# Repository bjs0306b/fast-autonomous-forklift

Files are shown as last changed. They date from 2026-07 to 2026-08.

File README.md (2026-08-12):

# F.A.S.T. — AI 무인 지게차 기반 디지털 트윈 물류 자동화 시스템

카메라와 거리계로 화물을 재고, 그 값으로 적재 위치를 정하고, 무인 지게차가 파렛트에 포크를 꽂아 옮기는 것까지를 한 줄로 이은 시스템이다. 측정·주행·제어·관제·시뮬레이션이 REST와 MQTT 두 가지 방식으로만 대화한다.

SSAFY 15기 공통 프로젝트 (2026-07 ~ 2026-08) · 6인 팀 · 프로젝트 코드 `S15P11A304`

> 실물은 1/10 스케일 미니어처 지게차와 창고다. 화물 측정은 실제 카메라·거리계로 하고, 다중 차량 운영은 Isaac Sim 디지털 트윈으로 시연한다.

---

## 무엇을 만들었나

| 덩어리 | 하는 일 |
|---|---|
| **측정 스테이션** | 지게차에 싣기 전 화물의 치수·전복 위험·편하중을 잰다. 카메라 + 거리계 + 검출 모델 |
| **무인 지게차** | Nav2로 목표까지 자율주행하고, 온보드 비전으로 파렛트 구멍을 찾아 포크를 꽂는다 |
| **클라우드 백엔드** | 작업을 만들고 차량에 배정하며, 측정 결과로 적재 위치를 정한다. 상태를 관제 화면에 중계한다 |
| **디지털 트윈** | 가상 창고에서 다중 지게차를 시뮬레이션하고, 실물 위치를 받아 반영한다 |

**아키텍처 다이어그램 →** [docs/아키텍처-다이어그램.md](docs/아키텍처-다이어그램.md)

---

## 측정한 결과

숫자는 전부 실물에서 잰 값이다. 시뮬레이션이나 공개 데이터셋 성능이 아니다.

| 항목 | 결과 | 목표 |
|---|---|---|
| 화물 치수 오차 | **평균 0.66 mm** / 최대 2.10 mm | ≤ 4 mm |
| 검출 성능 (실물 리그 평가셋) | **mAP@0.5 = 0.9898** (박스 0.9795 / 파렛트 1.0000) | — |
| 온보드 추론 (Jetson Orin Nano) | **GPU 10.18 ms** · 전처리 포함 종단 44.96 ms (22.2 fps) | ≤ 100 ms |
| 파렛트 구멍 검출 재현율 | **99.5 %** (220/221) | — |
| 파렛트 검출 재현율 / 오탐 | **100 %** (105/105) / 네거티브 120장에 **0 건** | — |
| 무인 측정 실물 검증 | 화물 높이 **92.3 mm** vs 실측 91.5 mm (**오차 0.8 mm**) | — |
| 포크 정렬 | **45° 로 돌아간 파렛트에 관통 성공** (재접근 9회, 표본 1회) | — |

---

## 실제로 어떻게 보이나

측정 스테이션이 화물을 보고 판단하는 화면이다. 박스와 파렛트를 각각 잡고, 거리계로 잰 거리로 화면 픽셀을 실치수로 바꾸고, 박스가 파렛트 위 어디에 얹혔는지로 편하중을 판정한다.

| 정상 적재 | 편하중 |
|---|---|
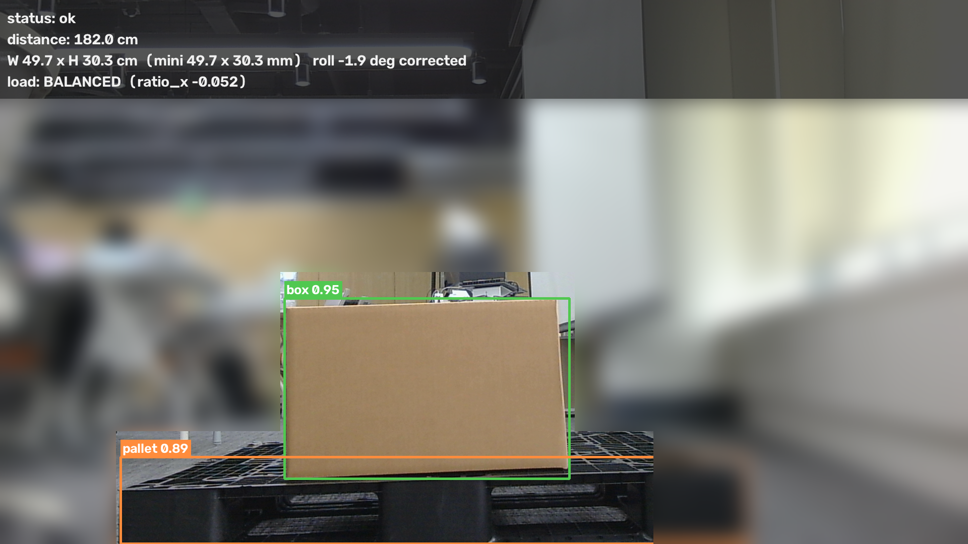
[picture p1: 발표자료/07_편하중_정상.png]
편하중 정상
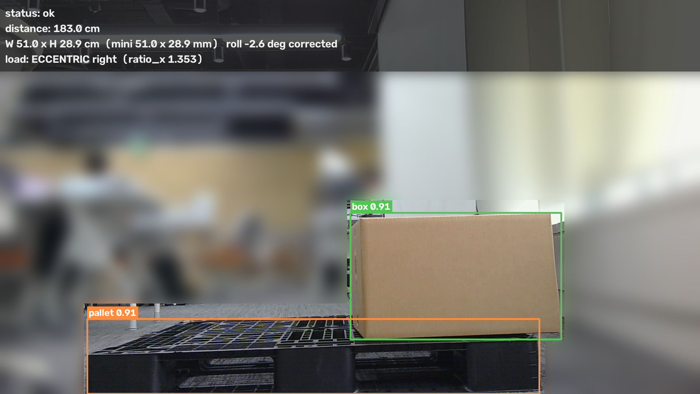
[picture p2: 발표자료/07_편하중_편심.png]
편하중 편심
|  |  |
| `load: BALANCED (ratio_x -0.052)` | `load: ECCENTRIC right (ratio_x 1.353)` |

같은 박스를 파렛트 오른쪽으로 밀어놓은 것만 다르다. 박스 중심과 파렛트 중심의 어긋남을 파렛트 폭으로 나눈 값(`ratio_x`)이 -0.052에서 1.353으로 뛰면서 `ECCENTRIC right`로 넘어간다.

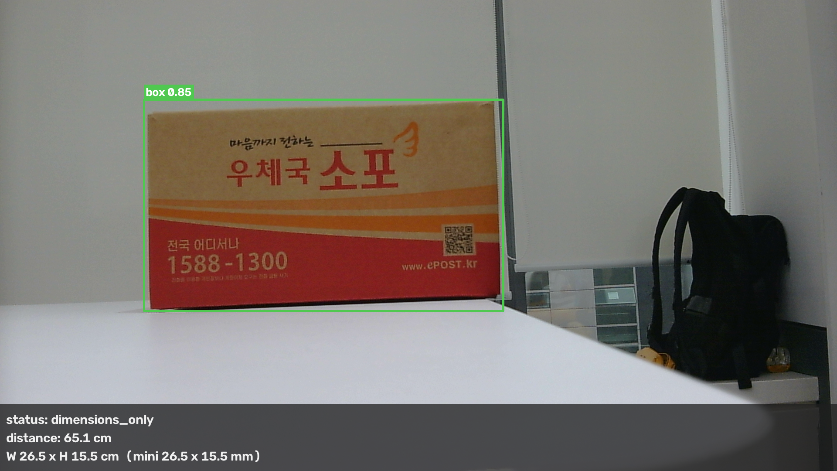
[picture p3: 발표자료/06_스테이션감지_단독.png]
스테이션 검출


파렛트 없이 박스만 있으면 `dimensions_only`로 떨어진다. 치수는 내지만 전복·편하중 판정은 하지 않는다 — 기준이 될 지지면이 없기 때문이다.

---

## 기술 스택

| 영역 | 사용 기술 |
|---|---|
| **AI · 비전** | RTMDet-m / RTMDet-s · MMDetection · MMDeploy · ONNX Runtime · TensorRT FP16 · OpenCV |
| **온보드** | Jetson Orin Nano (JetPack 6 / CUDA 12.6 / TensorRT 10.3) · ROS 2 Humble · Nav2 · AMCL · SLAM |
| **임베디드** | ESP32-S3 · ESP-IDF / FreeRTOS · PCA9685 PWM · MPU6500 IMU · MG996R 서보 |
| **백엔드** | Java 21 · Spring Boot 3.3.4 · MyBatis · MySQL 8 · Spring Integration MQTT (Eclipse Paho) |
| **프론트** | Next.js 16 · React 19 · TypeScript · Tailwind CSS 4 · shadcn/ui · STOMP over SockJS |
| **인프라** | AWS EC2 · Docker Compose · Eclipse Mosquitto 2 (MQTT over TLS) · MediaMTX · GitLab CI/CD · systemd |
| **시뮬레이션** | NVIDIA Isaac Sim 5.1 · Omniverse · USD |

---

## 팀과 기여 범위

6인 팀 프로젝트다. 커밋 이력 기준으로 각자 손댄 영역이 나뉜다.

| 담당 | 이름 | 주 영역 |
|---|---|---|
| **AI · 비전 · 제어** | 방지섭 (본인) | `ai/` · 스테이션 측정 · 온보드 추론 · 포크 정렬 제어 · 조향 펌웨어 |
| 백엔드 · 프론트 | 김재원 | `src/` · `frontend/` |
| 백엔드 · 프론트 | 전지웅 | `src/` · `frontend/` · AI 학습 데이터 수집 |
| ROS 2 · 임베디드 · 하드웨어 | 안제원 | `ros2_ws/` · `firmware/` · `3d_model/` |
| ROS 2 · 임베디드 | 전희창 | `ros2_ws/` · `firmware/` |
| 디지털 트윈 | 이준서 | `isaac_sim/` |

### 본인이 한 것

- **화물 측정 파이프라인** — 카메라·거리계·검출 모델을 묶어 치수·전복 위험·편하중을 내고, 세션을 열어 REST로 백엔드에 올리기까지. 무인 자동 측정(MQTT 트리거 → 정지 대기 → 촬영 → 전송 → 세션 종료)을 실물로 완주시켰다.
- **검출 모델 학습·승격** — 공개 데이터셋에서 시작해 실물 리그·가림 상황까지 도메인을 넓히며 재학습했다. 승격 조건을 착수 전에 못 박고(목표 도메인 지표 / 기존 성능 회귀 없음 / 망각 없음) 셋 다 통과할 때만 교체했다.
- **온보드 추론 이식** — 학습 산출물을 ONNX → TensorRT FP16으로 변환해 Jetson에 올리고, HTTP 추론 서버로 만들어 systemd 자동 기동까지 붙였다.
- **포크 정렬 제어** — 파렛트 구멍 두 개의 화면 좌표에서 좌우 오차와 요각을 기하로 계산해 `/cmd_vel`을 내는 상태기계(SEARCH → APPROACH → ALIGN → VERIFY → INSERT, 실패 시 RETREAT 후 재접근).
- **조향 펌웨어 수정** — 아래 트러블슈팅 참조.

---

## 기술적으로 어려웠던 것

포폴에 남길 값어치가 있는 것은 잘 된 것보다 **틀렸던 것을 어떻게 찾았나**라고 생각해서 세 개만 적는다.

### 1. 제어가 안 먹어서 게인을 이틀 의심했는데, 원인은 서보 펄스 범위였다

포크 정렬이 45° 틀어진 파렛트 앞에서 발산하고, ALIGN 상태에서 요각이 교정되지 않았다. 매끈한 사인파 형태의 진동이라 "폐루프 한계진동"으로 읽고 게인과 감쇠를 계속 만졌다.

실제 원인은 펌웨어의 `SERVO_MIN/MAX_PULSE_US`가 `1000~2000 µs`로 잡혀 있던 것이었다. MG996R은 `500~2500 µs`가 180°라, 코드가 28°라고 믿는 명령이 바퀴에서는 **8°**로만 나왔다 — 명령 대비 실제 회전이 `tan(8°)/tan(28°)` = **21~26 %**. 범위를 고치자 뒷바퀴 실각도가 36°가 되고 45° 파렛트 관통이 됐다.

**얻은 것**: 파라미터를 바꿔도 거동이 안 변하면 제어 루프 **밖**을 본다. 명령 단위와 물리 단위 사이 변환은 한 번은 자로 잰다 — 각도기로 바퀴를 재는 데 5분이면 됐을 일이었다. 이론적으로 옳은 추론(한계진동)이 오히려 조사를 루프 안에 가뒀다.

### 2. 모델이 못 잡는 것은 코드 문제가 아니라 데이터 분포 문제였다 (3회)

같은 종류의 실패를 세 번 겪었다. 책상 클로즈업 박스 미검출, 검은 플라스틱 파렛트가 **임계 0.02에서도 0건**, 화물이 파렛트를 덮으면 score 0.101. 매번 전처리와 임계를 먼저 의심했지만, 셋 다 학습셋에 그 분포가 없어서였다. 마지막 건은 학습셋의 가림률 30% 이상 샘플이 **0장**이었다.

**얻은 것**: 증상을 보면 코드보다 **학습셋 분포를 먼저 세어본다.** 그리고 오탐은 임계 상향이 아니라 기하 조건으로 거른다 — 임계를 0.5에서 0.7로 올리면 재현율이 95.5%에서 91.1%로 같이 깎였다.

### 3. 가장 비싼 버그는 에러를 안 내고 그럴듯한 답을 내는 것이었다

젯슨 추론 서버를 멀티스레드로 띄우자 pycuda의 CUDA 컨텍스트가 생성 스레드에 묶여 매 요청이 실패했는데, **예외가 아니라 검출 0개**로 나가고 서버는 HTTP 200을 응답했다. 클라이언트는 "물체가 없나 보다" 하고 넘어간다. 같은 날 비슷한 것을 다섯 건 더 잡았다 — 경로별 임계 불일치로 `ok`가 조용히 `dimensions_only`가 되고, 정지 판정 임계가 카메라 노이즈 바닥 아래라 "멎었다"가 영원히 성립하지 않고, 녹화 fps에 요청 상한값을 써서 영상이 1.45배 빨리 감겼다.

**얻은 것**: 실패를 성공처럼 보이게 하는 반환값(빈 목록·기본값·상한값)을 그대로 흘리지 않는다. 기동 자가진단을 넣고, 폴백·가정값은 화면과 로그에 항상 표시한다. 임계는 추측하지 말고 노이즈 바닥을 재고 정한다.

---

## 저장소 구조

```
ai/          검출 모델 학습·평가, 측정 스테이션, 온보드 추론, 포크 정렬 제어
src/         Spring Boot 백엔드
frontend/    Next.js 관제 대시보드
ros2_ws/     ROS 2 패키지 (MQTT 브리지, 텔레옵)
firmware/    ESP32-S3 모터 컨트롤러 (ESP-IDF)
isaac_sim/   디지털 트윈 · Nav2 시뮬레이션
infra/       MQTT 브로커 구성
3d_model/    출력용 하드웨어 파츠 (실물 사진 포함)
hardware/    미니어처 박스·파렛트 OpenSCAD 모델
scripts/     배포·점검 스크립트
docs/        설계·검증·운영 문서
발표자료/     발표용 스틸과 원고
```

## 문서

| 내용 | 경로 |
|---|---|
| 아키텍처 다이어그램 | [docs/아키텍처-다이어그램.md](docs/아키텍처-다이어그램.md) |
| 다이어그램 작성 명세 (블록·연결·검증 상태) | [docs/아키텍처-다이어그램-명세.md](docs/아키텍처-다이어그램-명세.md) |
| 요구사항 명세서 | [docs/요구사항명세서.md](docs/요구사항명세서.md) |
| 포크 정렬 설계 근거 | [docs/ai/onboard-fork-align-design.md](docs/ai/onboard-fork-align-design.md) |
| 온보드 TensorRT 절차 | [docs/ai/onboard-tensorrt-runbook.md](docs/ai/onboard-tensorrt-runbook.md) |
| 스테이션 측정 핸드오프 규격 | [docs/ai/station-measurement-handoff.md](docs/ai/station-measurement-handoff.md) |
| 화물 측정 연동 계약 | [docs/backend-message/cargo-measurement-workflow-contract.md](docs/backend-message/cargo-measurement-workflow-contract.md) |
| 관제 화면 와이어프레임 | [docs/와이어프레임-관제화면.md](docs/와이어프레임-관제화면.md) |
| 백엔드 README | [docs/backend-readme.md](docs/backend-readme.md) |
| 스프린트 회고 (KPT) | [docs/KPT/](docs/KPT/) |

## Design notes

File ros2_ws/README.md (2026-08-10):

# FAST ROS2 workspace

현재 패키지는 다음 두 개입니다.

| 패키지 | 역할 |
|---|---|
| `forklift_teleop` | `/cmd_vel`(`geometry_msgs/Twist`)을 ESP32 UART 명령으로 변환하고, ESP32 USB 텔레메트리를 `/imu/data`로 발행 |
| `fast_mqtt_bridge` | ROS2 상태·위치·경로와 백엔드 MQTT 명령/결과 연결 |

빌드:

```bash
cd ros2_ws
rosdep install --from-paths src --ignore-src -r -y
colcon build
source install/setup.bash
```

실행:

```bash
ros2 launch fast_mqtt_bridge mqtt_bridge.launch.py
ros2 launch forklift_teleop teleop_uart.launch.py
ros2 launch forklift_teleop sensor_usb.launch.py
```

`fast_mqtt_bridge`의 상세 설정, MQTT 토픽, 미연결 ROS2 adapter 범위는
[`src/fast_mqtt_bridge/README.md`](src/fast_mqtt_bridge/README.md)를 참고합니다.

LiDAR·좌우 전면 ToF·SLAM·Nav2·장애물 회피·10 Hz Orin 좌표 전송을 한 번에
기동하는 현장 절차는 [`FIELD_SLAM_MQTT.md`](FIELD_SLAM_MQTT.md)를 참고합니다.

## LiDAR AMCL 및 Nav2 통합 현황

2026-07-30 기준 `S15P11A304-98`과 `S15P11A304-99`에서 확인한
실차 위치 추정 및 주행 제어 통합 현황입니다.

### 지도

- 실차 시험 지도 설정: `maps/sim_warehouse_real.yaml`
- 지도 이미지: `maps/sim_warehouse.pgm`
- 해상도: `0.005 m/pixel`
- 지도 원점: `[0.0, 0.0, 0.0]`
- 지도 크기: `400 x 600 pixel` (`2.0 x 3.0 m`)

기존 `my_map.yaml`과 `my_map.pgm`은 이전 AMCL 연동 시험 기록을 위해
유지합니다. 새 실차 시험에서는 `maps/sim_warehouse_real.yaml`을
명시적으로 지정합니다.

지도 원점은 로봇의 출발 위치가 아닙니다. 수신한 지도 픽셀을 분석한 결과
다음 직선 시험 좌표는 장애물로부터 충분히 떨어진 자유 공간입니다.

- 출발 후보: `(x=0.618, y=0.618, yaw=0.0)`
- 가까운 목표 후보: `(x=0.818, y=0.618, yaw=0.0)`
- 이동 거리: `0.20 m`
- 출발점의 장애물 여유 거리: 약 `0.595 m`
- 목표점의 장애물 여유 거리: 약 `0.395 m`

실차 시험에서는 지게차를 지도의 출발 후보에 대응하는 실제 위치와
방향에 놓은 후 `/initialpose`를 발행해야 합니다. 좌표만 입력하고 실차를
다른 장소에 두면 AMCL 위치와 LiDAR 관측이 일치하지 않습니다.

### 확인 완료

- YDLiDAR `/scan` 발행 및 약 11 Hz 수신
- RF2O laser odometry의 `/odom` 발행
- `base_link -> laser_frame`, `odom -> base_link` TF 연결
- map server와 AMCL lifecycle `active`
- `/initialpose` 입력 후 `/amcl_pose` 및 `map -> odom` 생성
- Nav2 controller, planner, BT navigator, velocity smoother lifecycle `active`
- 실측 차체 footprint 적용
- 명시적인 안전 시작점과 목표점을 사용한 `ComputePathToPose` 성공

### 실측 좌표계

`base_link`는 전륜 구동축 중심입니다.

- `base_link`에서 포크 앞쪽 끝: `+0.190 m`
- `base_link`에서 차량 뒤쪽 끝: `-0.245 m`
- 차체 폭: 약 `0.148 m`
- `base_link`에서 LiDAR 중심: `x=-0.025 m`, `y=0.000 m`,
  `z=0.202 m`

차체 footprint:

```text
[[0.190, 0.074], [0.190, -0.074],
 [-0.245, -0.074], [-0.245, 0.074]]
```

### 다음 실차 시험

1. 지게차를 `maps/sim_warehouse_real.yaml`의 출발 후보에 대응하는
   물리적 위치와 방향에 놓습니다.
2. `(0.618, 0.618, 0.0)`을 `/initialpose`로 발행합니다.
3. `/amcl_pose`와 `map -> base_link` TF가 생성되는지 확인합니다.
4. `(0.818, 0.618, 0.0)`을 가까운 시험 목표로 사용합니다.
5. UART 브리지가 실행되지 않았는지 확인한 뒤 `NavigateToPose`를
   실행합니다.
6. 생성된 경로와 `/cmd_vel`만 관찰해 Nav2 비구동 시험을 완료합니다.

UART 비구동 시험 전 확인:

```bash
ros2 node list | grep uart_teleop_bridge
ros2 topic info /cmd_vel -v
```

`/uart_teleop_bridge`가 없어야 하며 `/cmd_vel`에 ESP32 UART 브리지
구독자가 없어야 합니다. 이 상태에서 별도 터미널로 다음 명령을 실행해
Nav2 출력만 확인합니다.

```bash
ros2 topic echo /plan
ros2 topic echo /cmd_vel
```

### 2026-07-30 검증 결과

- `(0.618, 0.618, 0.0)`을 `/initialpose`로 입력해 AMCL pose와
  `map -> odom -> base_link` TF 생성을 확인했습니다.
- 안전한 시작점과 목표점을 지정한 `ComputePathToPose`가 성공했습니다.
- Nav2 controller, planner, BT navigator, velocity smoother가 모두
  `active` 상태로 전환되는 것을 확인했습니다.
- 축거 `0.144 m`를 사용하는 후륜 조향 Ackermann 곡률 변환을 적용하고
  Python 단위 테스트 29개가 통과했습니다.
- 바퀴를 띄운 상태에서 수동 `/cmd_vel`을 UART 브리지로 전달해 전진,
  좌·우 조향, 정지 및 서보 중앙 복귀를 확인했습니다.
- DC 모터와 서보를 동시에 구동했으며 UART CRC/ACK 왕복 통신이
  정상적으로 유지됐습니다.
- `/cmd_vel` 발행 중단 후 500 ms watchdog에 의해 DC 모터가 자동으로
  정지하고 서보가 중앙으로 복귀하는 것을 확인했습니다.

### 2026-08-05 갱신 — 조향 실각도가 명령의 1/4이었다

`ros2_ws` 밖(펌웨어)의 문제였지만 **여기의 곡률 변환 전제가 깨져 있었다**.
`servo.c`가 각도를 180으로 정규화해 `SERVO_MIN/MAX_PULSE_US` 사이에 매핑하는데
그 범위가 `1000~2000 µs`였다. MG996R은 **500~2500 µs가 180°**다.

- 최대 조향을 명령했을 때 뒷바퀴 실측 **8°** (코드가 믿던 값 28°)
- 실효 회전반경 **1200~1450 mm** (설계값 537 mm의 2~3배)
- 명령 대비 실제 회전 **21~26%** = `tan(8°)/tan(28°)`

수정 후 값(`config/teleop.yaml`이 단일 출처):

| 항목 | 값 |
|---|---|
| 서보 펄스 범위 | `500~2500 µs` |
| `rear_steering_limit_deg` | `36.0` |
| `steering_center_cdeg` | `9000` (직진 편차 0.33°) |
| `steering_min/max_cdeg` | `5400 / 12600` (±36° 대칭) |
| `max_angular_rps` | `0.75` |
| `max_drive_percent` / `_reverse` | `60` / `100` |

⚠️ **조향 한계가 네 곳에 서로 다른 값으로 박혀 있었다.** `protocol.py`의 하드코딩이
범위 밖 명령에 `ValueError`를 던져 **브리지 프로세스를 죽이고 있었다**(증상은
"조향이 아예 안 움직임" — `/cmd_vel` 구독자가 사라진다). 지금은 **봉투**(`protocol.py`
·펌웨어)와 **운전값**(`teleop.yaml`)이 분리돼 있어 범위를 바꿔도 재플래시가 필요 없다.

⚠️ **경로 추종 게인을 이 이전에 잡았다면 다시 봐야 한다.** 같은 `angular_z`가 이제
4.5배로 돈다.

### 남은 실차 검증

- `NavigateToPose -> /cmd_vel -> UART bridge -> ESP32`를 동시에 연결한
  저속 자동 주행
- 🔴 **`/cmd_vel` 인계 규칙**(S15P11A304-**199**) — **셋이 얽혀 있다**(2026-08-06 갱신):

  | 주체 | 하는 일 |
  |---|---|
  | Nav2 | `/cmd_vel` 에 주행 명령 발행 |
  | `obstacle_avoidance`(109) | `/cmd_vel` 을 받아 감속·정지시켜 **`/cmd_vel_safe`** 로 중계 |
  | 포크 정렬(`onboard_fork_align_node.py`) | `/cmd_vel` 에 직접 발행 |

  ⚠️ **guard 를 띄우면 브리지가 `/cmd_vel_safe` 만 듣는다**(`obstacle_avoidance.launch.py`가
  `cmd_vel_topic` 을 덮어쓴다). 그 상태에서 포크 정렬은 guard 를 통과하게 되는데,
  guard 는 **0.45m 에서 정지 · 1.00m 부터 감속**한다. 정렬은 0.70m 에서 시작해 **0.21m 까지**
  들어가야 하므로 **파렛트를 장애물로 보고 막는다.** guard 가 틀린 게 아니라 역할이 겹친 것이다.

  지금 운용: 정렬 시간에는 Nav2 와 guard 를 내리고 `teleop_uart.launch.py` 로 브리지만 띄운다
  (`docs/ai/onboard-fork-align-runbook.md` §1·§1-2). 정렬 노드를 guard 뒤에 붙이려면
  `--cmd-topic /cmd_vel_safe`.
- ~~서보 명령각과 실제 후륜 바퀴각 캘리브레이션~~ → **완료**(위 2026-08-05 절)
- 지면에서 직선·곡선 경로 추종 오차 측정
- 후륜 조향 후미 스윙과 obstacle footprint 검증

---

## RViz 를 다른 PC 에서 띄우기

오린에서 RViz 를 돌리면 코어 하나를 통째로 먹는다. 그 부하로 스캔이 버려지면
`map->odom` 이 끊기고, 그러면 자세 추정이 통째로 흔들린다 — 화면을 보려다 보는
대상을 망가뜨린다. RViz 는 노트북에서 띄우고 오린은 ROS 만 돌린다.

### 노트북에 필요한 것

ROS 2 **Humble** (오린과 같은 배포판이어야 메시지 타입이 맞는다).

```bash
sudo apt install ros-humble-desktop ros-humble-nav2-msgs
```

`nav2-msgs` 는 `/local_costmap/voxel_grid`(`nav2_msgs/VoxelGrid`) 를 보려면
필요하다. 나머지 디스플레이는 전부 표준 메시지라 `desktop` 만으로 뜬다.
이 저장소를 노트북에 받을 필요는 없다 — 커스텀 메시지를 쓰지 않는다.

### 양쪽에 똑같이 넣을 환경변수

```bash
export ROS_DOMAIN_ID=100          # ⚠️ 오린과 반드시 같아야 한다
export ROS_LOCALHOST_ONLY=0
export FASTRTPS_DEFAULT_PROFILES_FILE=/경로/fastdds_no_shm.xml
```

⚠️ **`ROS_DOMAIN_ID` 가 도구마다 다르다.** 오린 프로필은 100 이고
`tools/field_lap_session.sh` 도 100 인데, `FIELD_SLAM_MQTT.md` 는 시뮬을 0 으로
쓴다고 적고 있다. 오린에서 `echo $ROS_DOMAIN_ID` 로 실제 값을 확인하고 맞출 것.
**틀리면 에러 없이 그냥 아무것도 안 보인다** — 가장 흔한 실패다.

⚠️ **DDS 프로파일을 노트북에도 걸 것.** 파일은
`src/forklift_teleop/config/fastdds_no_shm.xml` 이고, 노트북으로 복사해 그
경로를 가리키면 된다. 한쪽만 걸면 디스커버리가 반쪽이 되어 "토픽 목록은
보이는데 데이터가 안 온다" 가 된다.

### 같은 공유기에 있을 때

위 세 줄만 넣고 노트북에서 바로 확인한다.

```bash
ros2 topic list          # 오린 토픽이 보여야 한다
ros2 topic hz /scan      # 실제로 데이터가 흘러야 한다
rviz2 -d forklift.rviz   # 설정 파일은 오린에서 복사
```

### VPN 이나 다른 대역일 때 — 멀티캐스트가 안 된다

오린에는 Tailscale 대역(`100.x`)이 함께 잡혀 있다. **VPN 을 타면 DDS 의 기본
디스커버리(멀티캐스트)가 통하지 않아** 위 방법으로는 아무것도 안 보인다.
상대를 명시적으로 알려 주는 프로파일을 쓴다. 아래를 노트북의
`fastdds_peer.xml` 로 저장하고 `FASTRTPS_DEFAULT_PROFILES_FILE` 을 그것으로
가리킨다. `<address>` 에는 **노트북에서 오린으로 ping 이 되는 주소**를 넣는다.

```xml
<?xml version="1.0" encoding="UTF-8" ?>
<dds xmlns="http://www.eprosima.com">
  <profiles>
    <transport_descriptors>
      <transport_descriptor>
        <transport_id>udp_only</transport_id>
        <type>UDPv4</type>
      </transport_descriptor>
    </transport_descriptors>
    <participant profile_name="remote_rviz" is_default_profile="true">
      <rtps>
        <userTransports><transport_id>udp_only</transport_id></userTransports>
        <useBuiltinTransports>false</useBuiltinTransports>
        <builtin>
          <initialPeersList>
            <locator><udpv4><address>오린_IP</address></udpv4></locator>
          </initialPeersList>
        </builtin>
      </rtps>
    </participant>
  </profiles>
</dds>
```

오린 쪽에도 같은 방식으로 노트북 주소를 넣어 두면 양방향이 확실해진다.

### RViz 에서 볼 것

주행이 멈추면 이유가 최소 넷인데(가드·플래너·컨트롤러·브리지) 밖에서는 넷이
똑같이 "안 움직인다" 로 보인다. 아래 넷을 켜 두면 구분된다.

| 디스플레이 | 토픽 | 무엇을 답하는가 |
|---|---|---|
| MarkerArray | `/debug/hud` | **여섯 줄 요약** — 가드 판정·운전 주체·nav2 v/w·실제 서보 각도·경로 갱신 시각 |
| Path | `/plan` | 플래너가 경로를 냈는가 |
| Path | `/local_plan` | 컨트롤러가 실제로 따라가는 궤적 |
| Map | `/local_costmap/costmap` | 장애물이 실제보다 크게 잡히는가 |

`/debug/hud` 의 경로 줄은 점 수가 아니라 **마지막 갱신 후 경과**를 띄운다.
재계획 중인지 포기했는지는 그것만이 가른다.

점군(`/scan`, ToF)은 기본으로 꺼 둔다. 네트워크로 보내면 대역폭을 가장 많이
먹으면서 위 넷만큼 답을 주지 않는다.

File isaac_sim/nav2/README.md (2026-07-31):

# F.A.S.T. 시뮬 Nav2 설정 — 좌표·시작 위치

시뮬 창고와 지게차의 좌표 기준을 한곳에 모은 문서.
**세 곳(스크립트 spawn / Nav2 yaml / Isaac 씬 프림)의 값이 반드시 일치해야 한다.**
하나라도 어긋나면 Nav2 가 시작 위치를 잘못 잡아 목표를 거부한다.

## 축척

| | 크기 | 비고 |
|---|---|---|
| 시뮬 세계 (ff.usd) | 20 × 30 m | 실물의 10배 |
| 실물 목업 | 2 × 3 m | 미니어처 |
| **변환** | 실물 = 시뮬 / 10 | MQTT 경계에서만 적용 |

Nav2·맵·costmap 은 전부 **10배 세계(시뮬 좌표)** 에서 돈다.
실물 연동 시에만 좌표를 1/10 한다.

## 창고

| 항목 | 값 |
|---|---|
| 크기 | 20 m (X) × 30 m (Y) |
| 원점 (0,0) | 창고 왼쪽아래 구석 |
| 랙 줄 L | X 0.4~1.5, Y 8.5~24.5 (왼쪽) |
| 랙 줄 C | X 9.7~10.8, Y 8.5~24.5 (중앙) |
| 통로 | L-C 사이 약 8 m, C-오른쪽벽 약 8.7 m |

## 시작 위치 (SIM_F02)

| 항목 | 값 |
|---|---|
| **위치** | **x = 3.0, y = 2.0** (m, 시뮬 좌표) |
| **방향 (yaw)** | **0 rad** = +X (오른쪽, 창고 안쪽) |
| Z (높이) | 0.0 (씬에서 authored height 유지) |
| 실물 환산 | x = 0.3, y = 0.2 (÷10) |

시작점은 창고 아래쪽 빈 공간. 랙(Y 8.5~)보다 아래라 회전 여유가 충분하다.
+X 로 출발하면 통로를 따라 창고 안쪽으로 진입한다.

### 이 값이 들어가는 세 곳 (반드시 동일)

| 파일 | 항목 | 값 |
|---|---|---|
| `nav2/scripts/kinematic_vehicle.py` | `spawn=(x, y, yaw)` | `(3.0, 2.0, 0.0)` |
| `nav2/config/nav2_sim.yaml` | `amcl.initial_pose` | `x:3.0 y:2.0 yaw:0.0` |
| Isaac 씬 | `/World/Forklift_SIM_F02` Translate | `X:3.0 Y:2.0`, Rotate Z: `0` |

## 프레임 이름 (kinematic_vehicle.py 발행)

| 프레임 | 용도 |
|---|---|
| `SIM_F02_odom` | 오도메트리 원점 |
| `SIM_F02_base_link` | 차체 |
| `SIM_F02_laser` | 라이다 (씬 그래프에서 설정) |
| `map` | 전역 (map → SIM_F02_odom 은 static, run_nav2_static.sh) |

## 토픽 (네임스페이스 소문자: sim_f02)

| 토픽 | 방향 | 발행 주체 |
|---|---|---|
| `/sim_f02/cmd_vel` | 구독 | Nav2 → 차량 |
| `/sim_f02/odom` | 발행 | kinematic_vehicle.py |
| `/sim_f02/scan` | 발행 | **Isaac 씬 그래프 (라이다)** |
| `/tf`, `/tf_static` | 발행 | kinematic_vehicle.py |
| `/clock` | 발행 | Isaac 씬 그래프 |

주의: 차량 ID 는 ROS2 에서 `SIM_F02`(하이픈 불가), 네임스페이스는 소문자 `sim_f02`.

## 파일

```
nav2/
  make_map.py              맵 생성기 (obstacles.txt 읽어 pgm/yaml 생성)
  maps/
    obstacles.txt          라이다 높이(1.2m) 장애물 목록 (편집 가능)
    sim_warehouse.pgm      맵 이미지 (시뮬·실물 공용)
    sim_warehouse.yaml     시뮬용 (20×30m, 0.05 m/px)
    sim_warehouse_real.yaml 실물용 (2×3m, 0.005 m/px) — Orin 에 전달
    sim_warehouse.png       미리보기
  config/
    nav2_sim.yaml          Nav2 파라미터 (Ackermann/후륜조향)
  scripts/
    kinematic_vehicle.py   지게차 구동·odom·TF (Isaac Script Editor 에 붙여넣기)
    run_nav2_static.sh     Nav2 실행 (static map→odom, AMCL 미사용)
```

## 실행 순서

```
1. Isaac Sim: ff.usd 열기 + ForkliftC 를 (3,2,yaw0) 에 배치 + 라이다 그래프
2. Isaac Sim: Play
3. Script Editor: kinematic_vehicle.py 붙여넣고 실행
4. 터미널: ros2 topic list 로 /sim_f02/{odom,scan}, /tf, /clock 확인
5. 터미널: ./nav2/scripts/run_nav2_static.sh
6. RViz: 2D Goal Pose 로 목표 찍기
```

## 차량 운동 제원 (10배 세계)

미니어처 실측(포크 포함 전체 42cm = 차체 32 + 포크 10, 폭 15cm,
축거 14cm, 조향 60°)을 10배 한 값.

| 항목 | 값 | 근거 |
|---|---|---|
| 축거 (wheelbase) | 1.4 m | 14cm × 10, 후륜 조향 |
| 최대 조향각 | 1.047 rad (60°) | 실측 |
| **최소 회전반경** | **0.81 m** | = 1.4 / tan(60°) |
| 차체 크기 (footprint) | 3.2 × 1.5 m | 차체 32×15cm × 10 (포크 제외) |
| inflation_radius | 1.8 m | 외접원 1.77m 이상 |
| 최대 속도 | 2.0 m/s | |
| 포크 행정 | 0 ~ 1.0 m | 포크 10cm × 10 |

⚠️ 후륜 조향이라 **제자리 회전 불가**. Nav2 는 SMAC Hybrid-A* (DUBIN) +
Regulated Pure Pursuit 사용. `minimum_turning_radius: 0.81` 이 통로 폭과
연동되므로 함께 유지할 것.

⚠️ footprint 는 **차체(3.2m)** 기준. 포크(1m)는 제외 — 항상 장애물로 치면
팔레트 아래로 못 들어간다. 시작점 (3,2)는 아래벽까지 2m 로 외접원(1.77m)에
아슬아슬하니, 회전 시 벽에 스치면 (4,4) 로 옮길 것.

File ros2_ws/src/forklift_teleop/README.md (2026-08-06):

# Forklift Tele-operation & Sensor Bridge

노드가 두 개입니다.

| 노드 | 링크 | 역할 |
|---|---|---|
| `uart_teleop_bridge` | UART1 `/dev/ttyTHS1` | `/cmd_vel` → `@CMD` 명령 (하행) |
| `sensor_bridge` | USB CDC `/dev/ttyACM0` | `@IMU`/`@IMS` → `/imu/data`, `@TOF` → `/tof/{left,right}/points`, `@ENC` → `/wheel/twist` (상행) |

`uart_teleop_bridge`는 전륜 고정축·후륜 조향 차량의 전진/후진 조향 부호와
통신 안전 정지를 검증하기 위한 개방루프 텔레옵입니다.

`sensor_bridge`는 별도 프로세스입니다. 장치 파일이 다르므로 분리해도 되고,
그래야 텔레메트리 폭주가 명령 지연을 유발할 수 없고 동작 중인 텔레옵
경로를 건드리지 않습니다. 프레이밍·CRC는 `protocol.py`를 공유합니다.

**IMU와 ToF가 노드 하나인 이유**: `/dev/ttyACM0`은 한 프로세스만 열 수
있는데 `@IMU`·`@IMS`·`@TOF`가 모두 그 스트림 하나로 섞여 옵니다. 센서별로
노드를 나눌 수 없습니다.

## Build

```bash
cd ~/S15P11A304/ros2_ws
source /opt/ros/humble/setup.bash
rosdep install --from-paths src --ignore-src -r -y
colcon build --packages-select forklift_teleop
source install/setup.bash
```

## Run

터미널 1:

```bash
ros2 launch forklift_teleop teleop_uart.launch.py
```

터미널 2:

```bash
source /opt/ros/humble/setup.bash
ros2 run teleop_twist_keyboard teleop_twist_keyboard \
  --ros-args -p speed:=0.20 -p turn:=0.35
```

`teleop_twist_keyboard`의 제자리 회전 키는 차량 안전을 위해 정지·중앙
조향으로 처리됩니다. `/cmd_vel` 또는 UART가 500ms 이상 끊기면 ESP32가
모터를 정지하고 서보를 100도로 복귀시킵니다.

## UART (하행 명령)

- Jetson device: `/dev/ttyTHS1`
- 115200 baud, 8N1, no flow control
- ESP32-S3 TX GPIO17 -> Jetson Pin 10 RX
- ESP32-S3 RX GPIO18 <- Jetson Pin 8 TX
- Common ground is required

정확한 Ackermann 곡률과 속도 odometry는 이 패키지의 범위가 아닙니다.

## IMU 브리지 (상행 텔레메트리)

```bash
ros2 launch forklift_teleop sensor_usb.launch.py
```

`imu_bridge`와 `base_link → imu_link` static TF를 함께 띄웁니다.

- ESP32-S3 네이티브 USB를 Jetson에 연결하면 `/dev/ttyACM0`으로 잡힙니다
- 프레임 규격은 [펌웨어 README](../../../firmware/esp32/motor_controller/README.md) 참고
- ESP32 콘솔 로그가 같은 스트림으로 나오지만 `@`로 시작하지 않는 줄은 버립니다
- `idf.py monitor`가 포트를 잡고 있으면 이 노드가 열 수 없습니다

### 발행 내용

`/imu/data` (`sensor_msgs/Imu`)에 **자이로 Z만** 담습니다.

| 필드 | 값 |
|---|---|
| `angular_velocity.z` | 바이어스 보정된 요레이트 (rad/s) |
| `angular_velocity_covariance[8]` | `yaw_rate_stddev**2` (기본 4e-4) |
| `angular_velocity_covariance[0]`, `[4]` | 1e6 (미신뢰) |
| `orientation_covariance[0]` | -1.0 (ROS 관례: 이 필드 무효) |
| `linear_acceleration_covariance` 대각 | 1e6 (미신뢰) |

**covariance를 0으로 두면 안 됩니다.** EKF가 "오차 없는 완벽한 센서"로
착각하고 라이다 오도메트리를 완전히 무시합니다.

### ⚠️ `/wheel/twist` 는 발행만 되고 아무도 안 받는다 (2026-08-06 확인)

`@ENC`(50Hz)를 `wheel_diameter_m`·`encoder_counts_per_wheel_rev` 로 환산해
`/wheel/twist` 로 냅니다. 그런데 **구독자가 하나도 없습니다** — `ekf.yaml` 에
`twist0` 항목이 없고 Nav2 도 받지 않습니다. 지금 병진 속도는 전적으로
rf2o(라이다 오도메트리)에서 나옵니다.

의도인지 미완인지 기록이 없어 **건드리지 않았습니다.** EKF 에 붙이는 방법은
`config/ekf.yaml` 주석에 적어뒀습니다.

⚠️ 붙이기 전에 **정지 상태에서 두 소스의 `vx` 를 비교**하세요. 미니어처는 바닥
마찰이 약해 바퀴가 헛돌면 엔코더가 실제보다 빠르게 읽힙니다 — 그 상태로 융합하면
라이다가 맞는데도 EKF 가 "가고 있다" 고 믿습니다.

### 시각 보정

ESP32는 자체 시계를 쓰므로 `esp_timer` 값을 그대로 쓰면 ROS 시각과 어긋나고
TF가 조용히 망가집니다. `ClockOffsetTracker`가 `host - mcu` 차이의 **최소값**을
추적해 큐잉 지연을 걷어내고, 20ppm 상향 여유로 클럭 스큐를 따라갑니다.
MCU 리부트(시간 역행)나 1초 이상 점프는 리셋으로 처리하며, 스탬프는 절대
미래로 가지 않습니다.

### 부호 확인 (건너뛰지 말 것)

```bash
ros2 topic echo /imu/data --field angular_velocity.z
```

위에서 봤을 때 **반시계 회전이 양수**여야 합니다(REP-103). 반대로 나오면
`config/sensors.yaml`의 `gyro_z_sign`을 `-1`로 바꿉니다.

참고: 부호를 뒤집으려고 static TF의 **yaw를 180도 돌리는 것은 효과가
없습니다.** Z축 회전은 ωz 부호를 바꾸지 않습니다. 센서를 물리적으로 뒤집어
장착했다면 `roll`을 π로 주는 것이 맞습니다.

## 전면 ToF (VL53L8CX ×2)

`sensor_usb.launch.py`가 같이 띄웁니다. `/tof/left/points`·`/tof/right/points`에
`sensor_msgs/PointCloud2`로 센서당 15Hz 발행합니다.

- 존 8×8을 3D 점으로 투영합니다. **LaserScan이 아닌 이유**는 존의 고도 정보가
  남아야 바닥 반사를 거르고 라이다와 같은 costmap에서 서로를 지우지 않기
  때문입니다 (아래 참고)
- `target_status == 5`만 통과시킵니다. 9(신뢰도 절반)는
  `tof_accept_low_confidence`로 켤 수 있습니다
- 유효하지 않은 존은 NaN으로 채우지 않고 **버립니다** — costmap이 유령 반환을
  보지 않게 합니다

### 확인해야 할 것 두 가지

**`tof_fov_deg`** — 데이터시트 실제 값과 대조합니다. 틀리면 모든 방위가
통째로 어긋납니다.

**`tof_azimuth_sign` / `tof_elevation_sign`** — 존 격자가 어느 방향으로
도는지는 센서 장착 방향에 달렸습니다. 열·행 순서가 뒤집힌 것은 **회전이 아니라
거울상이라 static TF로 고칠 수 없습니다.** 알려진 방위에 상자를 놓고 RViz에서
그 방위에 찍히는지 확인한 뒤 확정합니다. 자이로 `gyro_z_sign`과 같은 성질입니다.

### 라이다와의 관계

두 센서는 판단을 나누지도, 측정을 융합하지도 않습니다. **같은 costmap에 각자
`observation_source`로 등록**되고 플래너는 병합된 격자 하나만 봅니다.

조정이 필요한 곳은 clearing 한 곳입니다. 낮은 상자 위로 라이다 빔이 지나가면
라이다는 그 칸을 비었다고 raytrace clearing 하는데, **평면 레이어라면 ToF가
marking 해둔 상자가 지워집니다.** local costmap이 `VoxelLayer`라 marking·clearing이
복셀 단위로 일어나 이걸 피합니다 — 라이다(z≈0.2)와 ToF(z≈0.05~0.15)가 서로
침범하지 않습니다.

`nav2_params.yaml` 연결은 이 패키지 범위 밖입니다. 붙일 때 주의점:
- ToF는 `clearing: False`로 시작합니다. 45° 원뿔이 공격적으로 clearing 하면
  시야 가장자리 밖의 유효한 라이다 장애물을 지웁니다
- global costmap(평면 `ObstacleLayer`)에는 **추가하지 않습니다.** 높이가 접혀
  위 문제가 되살아나고, ToF는 매핑 센서가 아니라 단거리 반응 센서입니다
- 라이다 높이를 바꾸면 `lidar_odometry.launch.py`의 `LIDAR_TRANSLATION`을
  실측으로 갱신하고, VoxelLayer 천장 0.8m와 ToF 대비 최소 0.10~0.15m 간격을
  지키는지 확인합니다

### 범위 밖

EKF(`robot_localization`) 구성은 이 패키지에 없습니다. 붙일 때는 rf2o의
`publish_tf`를 `false`로 내려 `odom → base_link` 발행 주체를 EKF 하나로
정리해야 합니다. 둘이 동시에 발행하면 TF가 떨며 튑니다.

## 상부 LiDAR + 정면 ToF 장애물 회피 (S15P11A304-109)

센서 배치는 다음과 같다.

```text
                진행 방향 +X
                      ↑
       정면 좌 ToF  [차량/포크]  정면 우 ToF
                      │
                 상부 YDLIDAR
```

두 ToF는 측면을 보지 않는다. 둘 다 포크 방향(+X)을 보며, 상부 LiDAR의 스캔
평면 아래에 있는 포크·낮은 상자·사람 다리 등의 전방 사각지대를 보완한다.

`obstacle_avoidance`의 역할은 다음과 같다.

- 상부 YDLIDAR: 좌·우 우회 공간 및 스캔 높이에 걸리는 구조물 확인
- 정면 좌/우 ToF: 각 포크 측 전방의 낮은 장애물 거리 확인
- 좌 ToF만 가까우면 우회 후보는 우측, 우 ToF만 가까우면 좌측
- 후보 방향을 상부 LiDAR가 비어 있다고 확인해야만 조향 보정
- 두 정면 ToF가 모두 막히거나 후보 방향도 LiDAR에서 막히면 감속 또는 정지
- 모든 센서 점은 TF를 통해 `base_link`로 변환하므로 실제 전방 장착 위치가 반영됨

명령 경로는 아래처럼 분리한다.

```text
Nav2/teleop /cmd_vel
        → obstacle_avoidance
        → /cmd_vel_safe
        → uart_teleop_bridge
```

기본 임계값은 0.45m 정지, 1.0m부터 감속, 센서 0.5초 stale 시 정지다.
ToF PointCloud2 두 개는 local VoxelLayer에만 marking source로 추가한다. 이로써
상부 LiDAR가 지나친 낮은 전방 물체도 Nav2가 경로 장애물로 사용한다. ToF clearing은
다른 센서의 유효 장애물을 지우지 않도록 비활성화한다.

빌드 및 실행:

```bash
cd ~/S15P11A304/ros2_ws
source /opt/ros/humble/setup.bash
colcon build --packages-select forklift_teleop
source install/setup.bash

# 터미널 1: 상부 YDLIDAR + RF2O + EKF
ros2 launch forklift_teleop lidar_odometry.launch.py

# 터미널 2: 정면 ToF 2개 + IMU
ros2 launch forklift_teleop sensor_usb.launch.py

# 터미널 3: 회피 노드 + 안전 cmd_vel을 받는 UART 브리지
ros2 launch forklift_teleop obstacle_avoidance.launch.py
```

상태 확인:

```bash
ros2 topic echo /obstacle_avoidance/status
ros2 topic echo /cmd_vel_safe
```

현재 카메라 모델은 `pallet/hole` 전용이므로 사람·차량 분류 검증에는 사용할 수
없다. 사람·차량 모델이 준비되면 `/camera/obstacles`에 아래 JSON을 발행하고
`config/obstacle_avoidance.yaml`의 `require_vision`을 `true`로 바꾼다.

```json
{"detections":[{"label":"person","confidence":0.93,"distance_m":0.8}]}
```

실차 장착 전에 `sensor_usb.launch.py`의 ToF x/y/z와
`lidar_odometry.launch.py`의 LiDAR x/y/z를 반드시 실측값으로 교체해야 한다.

---

## 무인 완주 시나리오 — `unmanned_mission` (2026-08-06 문서화)

`Nav2 로 집는 곳까지 → 포크 올림 → 내리는 곳까지 → 포크 내림` 을 **한 번에** 실행하는
노드다. 코드는 있었는데 문서가 없어 여기 적는다.

```bash
ros2 run forklift_teleop unmanned_mission --ros-args \
    -p mission_armed:=true \
    -p pickup_x:=1.2 -p pickup_y:=0.8 -p pickup_yaw:=0.0 \
    -p dropoff_x:=2.4 -p dropoff_y:=1.6 -p dropoff_yaw:=1.57
```

### 안전장치 (이미 들어 있는 것)

| 장치 | 동작 |
|---|---|
| `mission_armed` | **기본 false.** 명시적으로 true 를 주지 않으면 아무것도 안 하고 끝난다 |
| 좌표 검사 | 집는 곳과 내리는 곳이 **0.05m 미만이면 거부** |
| 브리지 대기 | 포크 브리지가 안 떠 있으면 시작 안 함 |
| `start_delay_sec` 5초 | 팔을 뺄 시간. 이때 *"포크 호밍됐는지, 경로가 비었는지"* 경고 로그가 나온다 |
| 포크 타임아웃 30초 | 응답이 없으면 `STOP` 을 보내고 실패로 끝낸다 |
| `finally` 의 `STOP` | Ctrl-C 로 끊어도 포크는 멈춘다 |

### ⚠️ 이 시나리오는 포크 정렬을 쓰지 않는다

Nav2 로 목표 자세에 도착한 뒤 **바로 포크를 올린다.** 파렛트 구멍을 보고 맞추는
`onboard_fork_align_node.py` 는 이 경로에 없다. 즉 **데모 경로가 두 갈래다**:

| | 무인 완주(`unmanned_mission`) | 포크 정렬(`onboard_fork_align_node`) |
|---|---|---|
| 위치 정확도 | Nav2 목표 자세에 의존 | 카메라로 구멍을 보고 수렴 |
| 파렛트가 돌아가 있으면 | 못 맞춘다 | 45° 까지 관통 확인(08-05) |
| `/cmd_vel` 발행자 | Nav2 | 정렬 노드 |
| guard 와의 관계 | 그대로 통과(먼 거리 주행) | **0.45m 에서 막힌다** — 아래 참조 |

⚠️ **둘을 한 번에 이으려면 `/cmd_vel` 인계 규칙이 필요하다**(S15P11A304-**199**).
지금은 사람이 런치를 갈아 띄운다. 정렬 구간에서 guard 를 어떻게 할지는
`docs/ai/onboard-fork-align-runbook.md` §1-2 참조.

### 포크 명령 경로

`/fork/command`(String: `UP`·`DOWN`·`HOME`·`INITIALIZE`·`STOP`) → 브리지 → `@LIFT` UART
→ 펌웨어. 결과는 `/fork/status` 로 돌아온다(`RUNNING`·`DONE`·`ERROR`).

⚠️ **`@LIFT` 는 1회성이라 펌웨어가 거부하면(`@ACK,...,ERROR`) 재전송이 없다.** 미션은
`/fork/status` 를 기다리다 30초 타임아웃으로 실패 처리한다 — 포크가 안 움직이면
브리지 로그를 볼 것(`firmware/esp32/motor_controller/README.md` UART 절).

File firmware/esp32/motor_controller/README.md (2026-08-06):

# ESP32 Forklift Motor Controller

ESP32-S3에서 전륜 DC 구동 모터, 후륜 서보 조향, 포크 리니어 스텝모터를 제어하고 MPU6500 자이로를 상행 발행하는 ESP-IDF 프로젝트입니다. Jetson의 ROS2 텔레옵 노드가 UART로 보낸 최신 명령만 실행하며, 통신이 끊기면 자동 정지합니다.

보드는 **Geekble nano ESP32-S3**(Arduino Nano ESP32 풋프린트)입니다. GPIO15·16은 헤더에 나오지 않으므로 배선 시 아래 표를 그대로 따릅니다.

## 링크 구조

방향에 따라 물리 링크가 다릅니다.

| 방향 | 링크 | 내용 |
|---|---|---|
| Jetson → ESP32 | UART1 (GPIO17/18, 115200 8N1) | `@CMD` 명령, 20Hz |
| ESP32 → Jetson | UART1 | `@ACK` 응답 |
| ESP32 → Jetson | **네이티브 USB CDC** (`/dev/ttyACM*`) | `@IMU` 100Hz, `@IMS` 1Hz, `@TOF` 센서당 15Hz, `@ENC` 50Hz |

센서 상행을 USB로 분리한 이유는 대역폭입니다. 나중에 VL53L8CX ToF 2개(8×8 멀티존)가 붙으면 115200 UART로는 들어가지 않습니다. 제어 경로는 UART1에 그대로 남겨 텔레메트리 폭주가 명령 지연을 유발할 여지를 없앱니다.

USB 커넥터가 하나뿐인 보드라 **콘솔도 같은 USB로 나갑니다.** `ESP_LOG` 줄과 프레임이 섞이지만, `usb_serial_jtag_write_bytes()`가 전부-아니면-전무로 기록하므로 프레임이 중간에 잘리지 않습니다. Jetson 파서는 `@`로 시작하지 않는 줄을 버립니다. `idf.py monitor`와 ROS2 노드는 같은 장치를 쓰므로 동시에 열 수 없습니다.

## 하드웨어 연결

- I2C0: SDA GPIO8(D5), SCL GPIO9(D6) — Motor HAT + 서보 PCA9685
- Jetson UART1: TX GPIO17(D8), RX GPIO18(D9), GND 공통
- UART 설정: 115200 bps, 8N1, flow control 없음
- 구동 모터: Waveshare Motor Driver HAT의 Motor B
- 조향 서보: 별도 PCA9685 채널 0
- 포크 스텝퍼(TMC2209): STEP GPIO4, DIR GPIO5, EN GPIO6, 하한 스위치 GPIO7

### IMU (MPU6500 / MPU9250) — SPI2

```text
MPU6500      보드 표기   GPIO
---------    ---------   ----
SCK      <--  D13         48
SDI/MOSI <--  D11         38
SDO/MISO -->  D12         47
NCS      <--  D10         21
INT      -->  D7          10
VCC      <--  3V3
GND      <->  GND
```

- 레지스터 접근 1MHz, 데이터 버스트 8MHz. D13(GPIO48)은 온보드 LED와 공유되므로 `WHO_AM_I`가 간헐적으로 실패하면 `IMU_SPI_DATA_CLOCK_HZ`를 4MHz로 낮춥니다
- A4·A5(GPIO11·12)는 나중 ToF용 I2C1로 비워 둡니다
- 자기계(AK8963)는 연결하지 않습니다. 모터 코일·스텝퍼·리니어 스크류가 자기장을 교란하고, 절대 방위는 AMCL이 더 정확하게 잡습니다
- **장착**: 회전 중심에 가깝게, 볼트 또는 강한 접착으로 고정합니다. 양면테이프는 진동이 노이즈로 들어옵니다. 스텝퍼 드라이버·DC-DC 컨버터에서 최대한 떼고, SPI 케이블을 스텝퍼 케이블과 나란히 배선하지 않습니다
- Z축이 위(+)를 향하게 장착합니다. 부호가 반대로 나오면 펌웨어를 고치지 말고 브리지의 `gyro_z_sign` 파라미터로 처리합니다

ESP32-S3를 USB-C로 공급할 때는 Jetson 및 모터 HAT과 GND만 공통으로 연결합니다. 서로 다른 5V 또는 3.3V 전원 출력을 직접 연결하지 않습니다.

## UART 명령

```text
@CMD,<seq>,<signed_pwm>,<servo_cdeg>*<CRC16>\n
```

- `signed_pwm`: **봉투는 `-100`~`100`**(`TELEOP_MAX_DRIVE_PERCENT`). 양수 전진, 음수 후진.
  운전값은 `teleop.yaml` 이 정한다 — **전진 60 · 후진 100**(꺾은 채 후진은 저항이 커
  60% 로는 못 움직인다, 2026-08-05).
- `servo_cdeg`: **봉투는 `4000`~`14000`**(`TELEOP_STEERING_MIN/MAX_CDEG`).
  운전값은 `teleop.yaml` — **중립 `9000` · 좌우 `5400`~`12600`**(±36°).

> ⚠️ **봉투(펌웨어·`protocol.py`)와 운전값(`teleop.yaml`)은 다르다.** 봉투는 "여기까지
> 허용", 운전값은 "실제로 쓰는 범위"다. 2026-08-05 이전에는 같은 한계가 네 곳에 서로
> 다른 값으로 박혀 있었고, `protocol.py` 하드코딩이 범위 밖 명령에 `ValueError` 를 던져
> **브리지 프로세스를 죽이고 있었다**(증상은 "조향이 아예 안 움직임"). 이제 분리돼
> 있어 운전 범위를 바꿔도 **재플래시가 필요 없다.**
>
> ⚠️ 종전 이 문서에 적혀 있던 `8500`~`11500` · 중앙 `10000` 은 **2026-08-04 이전 값**이다.
> 중립은 10000 → 9600 → 9400 → **9000** 으로 세 번 바뀌었다(197 · 198 · 152).
> 현재 값은 언제나 `ros2_ws/src/forklift_teleop/config/teleop.yaml` 을 본다.
- CRC: `CMD`부터 마지막 필드까지 CRC-16/CCITT-FALSE
- 응답은 **두 가지**입니다 (2026-08-06 확인):
  - `@ACK,<seq>,OK*<CRC16>\n` — 명령이 모터 태스크 큐에 들어갔다
  - `@ACK,<seq>,ERROR*<CRC16>\n` — **프레임은 멀쩡한데 실행을 거부했다**(큐 제출 실패 등)

⚠️ **프레임 자체가 깨졌으면 아무 응답도 없습니다.** 잘못된 CRC·잘린 프레임·과도하게 긴
프레임·범위 밖 값은 시퀀스를 읽을 수 없거나 신뢰할 수 없으므로 **조용히 버립니다.**
즉 "응답이 없다"와 "ERROR 응답"은 원인이 다릅니다 — 전자는 배선·전송 문제, 후자는
펌웨어가 명령을 받고도 못 한 것입니다.

⚠️ **`ERROR` 응답에 재전송은 없습니다.** 브리지(`uart_teleop_bridge`)는 ROS 로그에
`warning` 을 남기고 넘어갑니다.

- **구동·조향(`@CMD`)** 은 20Hz 로 계속 나가므로 한 번 거부돼도 다음 프레임이 덮습니다.
- **포크(`@LIFT`)** 는 **1회성**입니다. 거부되면 그 동작은 **그대로 사라지고** 경고 로그만
  남습니다 — 포크가 안 움직이면 `ros2 topic echo` 가 아니라 **브리지 로그**를 볼 것.

유효한 명령만 모터 태스크의 최신 명령 큐에 전달하고 watchdog을 갱신합니다.

### 포크 원점·초기화 명령

```text
@LIFT,<seq>,UP|DOWN|HOME|INITIALIZE|STOP*<CRC16>\n
```

- `HOME`: 포크를 **하한 홈 스위치가 눌릴 때까지** 아래로 이동한다. 최대
  `STEPPER_MOTOR_HOMING_MAX_STEPS` 안에 스위치가 눌리지 않으면 `ERROR`로 끝난다.
- `INITIALIZE`: 주행 모터를 정지하고 조향 서보를 **중앙**으로 돌린 뒤 `HOME`을 실행한다.
  중앙 각도는 `TELEOP_STEERING_CENTER_CDEG`를 그대로 쓴다(현재 **90°**) — 코드가 상수를
  참조하므로 중립을 옮기면 따라온다. 종전 이 줄의 "100°"는 옛 중립이다(2026-08-06 정정).
- 하한 스위치가 눌리면 즉시 정지한 뒤 500 ms 후 소폭 상승해 스위치를 해제하고 `DONE`을 보고한다.
- 상한 스위치는 사용하지 않는다. 상승 이동 범위는 명령 step 수와 기구적 안전 범위로 관리한다.

## USB 센서 상행 프레임

프레이밍과 CRC는 UART 명령과 동일합니다(`frame_codec.c` 공유). 모든 필드는 10진수입니다.

```text
@IMU,<seq>,<t_us>,<gz_mdps>,<temp_cdeg>*<CRC16>\n     100Hz
@IMS,<who_am_i>,<bias_mdps>,<idle>,<dropped>,<seq>*<CRC16>\n   1Hz
@TOF,<sensor_id>,<seq>,<t_us>,<256자리 16진수>*<CRC16>\n   센서당 15Hz
@ENC,<seq>,<t_us>,<count>,<read_errors>*<CRC16>\n     50Hz
```

| 필드 | 의미 |
|---|---|
| `seq` | uint32 샘플 카운터. 건너뛰면 드롭 |
| `t_us` | 데이터 준비 인터럽트 시점의 `esp_timer_get_time()` (µs). Jetson이 ROS 시각으로 변환 |
| `gz_mdps` | 바이어스 보정된 자이로 Z, milli-dps. ±250dps·131 LSB/dps → 분해능 약 7.6 mdps |
| `temp_cdeg` | 칩 온도 centi-°C. 바이어스 온도 드리프트 진단용 |
| `who_am_i` | 0x70=MPU6500, 0x71=MPU9250, 0x73=MPU9255 (10진수로 전송) |
| `bias_mdps` | 현재 자이로 Z 바이어스 추정값 |
| `idle` | 정지 감지 상태(1이면 바이어스 갱신 중) |
| `dropped` | 누적 드롭 수(큐 만원 또는 USB 링버퍼 만원) |
| `sensor_id` | 0=좌, 1=우 |
| 존 4자리 | 거리 3자리(mm, 0~4095) + 타깃상태 1자리, 구분자 없음. row-major, row 0 = 상단 |
| `count` | 휠 엔코더 PCNT 누적 카운트(부호 있음). 하드웨어 카운터가 ±16000에서 감기므로 **차분으로 쓴다** |
| `read_errors` | 엔코더 읽기 실패 누적. 100회마다 한 번만 로그를 남긴다 |

`@TOF`는 존당 고정폭이라 길이가 결정적이고 필드 분해가 필요 없습니다. 센서당 약
290바이트 × 15Hz × 2 = **8.7KB/s**로, UART 115200이었다면 불가능한 양입니다.

### 전면 ToF (VL53L8CX ×2)

I2C1(A4·A5)에 두 개를 답니다. **I2C0은 Motor HAT·서보 전용으로 남깁니다** — 8×8
블록 전송이 서보 갱신 뒤에 줄을 서면 샘플 간격이 무너집니다.

**배선** (SATEL 계열 브레이크아웃 기준)

```text
VL53L8CX      보드 표기   GPIO
MOSI_SDA  <->  A4          11    풀업 필요 (아래)
MCLK_SCL  <->  A5          12    풀업 필요
LPn       <--  A6 / A7     13/14 좌 / 우
INT       -->  A0 / A1     1/2   좌 / 우
SPI_I2C_N <--  GND         -     I2C 모드 선택
NCS       <--  3V3         -     SPI 비활성
MISO           미연결      -     SPI 전용
```

**`SPI_I2C_N`을 반드시 GND에 내리세요 — 센서마다 각각.** 이 핀이 플로팅이면 센서가
I2C와 SPI 모드를 오가면서 증상이 실행마다 바뀝니다: 쓰기는 ACK를 받는데 주소가 남지
않고, 스캔과 프로브가 서로 다른 답을 내고, 옆 센서를 깨우면 멀쩡하던 센서가 사라집니다.
브링업에서 가장 오래 걸린 함정이었습니다.

풀업은 현재 배선 길이에서 **불필요**합니다. 내부 풀업만으로 400kHz에서 84KB 펌웨어
업로드가 센서당 2.4초에 통과합니다. 케이블을 길게 뽑아 불안정해지면 그때
SDA→3.3V, SCL→3.3V에 2k를 **버스 전체에 한 쌍**만 답니다(센서마다 아님).
브레이크아웃에 이미 풀업이 있으면 추가하지 마세요 — 병렬로 1.1kΩ 아래가 되면
VL53L8CX의 싱크 전류 한계를 넘습니다.

**주소 분리** — 두 센서 모두 기본 0x29라 순차 초기화가 필요합니다. 이 보드에는
PWREN이 없어 소프트웨어로 전원을 끊을 수 없고, **ESP32만 재부팅되면 센서는 이전
실행의 주소를 그대로 갖고 있습니다.** 그래서 리셋 대신 프로브로 해결합니다.

1. 둘 다 LPn을 내려 침묵
2. 한쪽만 LPn을 올림 → 아직 기본 주소인 건 그 센서 하나뿐
3. 목표 주소부터 프로브 → 어느 쪽이 나오든 원하는 주소로 이설
4. **깨운 채로 두고** 다음 센서를 올려 반복
5. 전부 깨어난 뒤 초기화

**LPn을 다시 내리면 안 됩니다.** 배정한 주소는 통신 블록에 휘발성으로 저장되는데
LPn이 그 블록의 전원을 내리므로, 침묵시키는 순간 **주소가 0x29로 되돌아갑니다.**
그래서 센서를 하나씩 깨워 누적시킵니다 — 매번 기본 주소에 남아 있는 건 방금 깨운
센서 하나뿐이라 충돌이 없습니다.

부팅 시 두 센서 모두 기본 주소에서 시작하므로 재부팅을 반복해도 안전합니다.

**함정**: `vl53l8cx_set_i2c_address()`는 **쓰면 안 됩니다.** 이 함수는

```c
WrByte(0x7fff, 0x00);            // 구 주소 — 성공
WrByte(0x04, new_addr >> 1);     // 여기서 센서가 이사함
platform.address = i2c_address;  // 구조체만 갱신
WrByte(0x7fff, 0x02);            // 구 핸들로 전송 → NACK
```

세 번째 쓰기를 이미 이사한 센서의 옛 주소로 보냅니다. 전송은 `platform.address`가
아니라 `platform.handle`로 나가는데, i2c_master는 등록 시점 주소에 핸들을 고정하기
때문입니다. 실패할 뿐 아니라 **페이지 레지스터가 잘못된 상태로 남습니다.**

`vl53l8cx_pair.c`의 `tof_change_address()`가 같은 세 레지스터를 쓰되 **센서가
이사한 직후 핸들을 재등록**합니다. 컴포넌트 예제에서도 이 호출이 주석 처리돼
있어 미검증으로 보입니다.

부팅 시 센서당 펌웨어 블롭이 I2C로 올라가 400kHz에서 1~2초 걸립니다. 그래서 ToF는
호밍·IMU 뒤 **마지막에** 기동하고, 실패해도 주행은 계속됩니다.

> 🔴 **단, 그건 펌웨어까지의 이야기입니다** (2026-08-06 추가). ROS2 쪽에서
> `obstacle_avoidance` guard 를 띄우면 **ToF 가 하나만 죽어도 차가 안 갑니다** —
> `require_both_front_tof: true` 라 0.5초간 데이터가 없으면 `SENSOR_TIMEOUT` 으로
> 0 Twist 를 냅니다. 둘 다 의도된 동작이지만 방침이 반대라, 이 문장만 읽고
> "ToF 없어도 굴러간다" 고 판단하면 원인을 모터에서 찾게 됩니다.
>
> 증상이 "명령은 나가는데 안 움직임" 일 때 먼저 볼 것:
> `ros2 topic echo /obstacle_avoidance/status` — `reason` 에 어느 센서인지 나옵니다.

자이로 X·Y와 가속도, 자기계는 발행하지 않습니다. `two_d_mode` EKF에서 쓰이지 않고, 모터·스텝퍼 진동이 가속도 신호를 크게 오염시키며 병진 속도는 rf2o가 더 잘 줍니다.

### 바이어스 처리

바이어스가 0.5 dps만 남아도 1분에 약 30도가 틀어집니다. 요(yaw)는 자이로 말고 대안이 없으므로 두 단계로 처리합니다.

> ⚠️ 종전 이 자리에 *"엔코더가 없어"* 라고 적혀 있었는데 **지금은 휠 엔코더가 있습니다**
> (`@ENC` 50Hz, S15P11A304-109 계열에서 추가). 다만 엔코더는 **주행 거리·속도**를 주고
> **요 각도는 못 줍니다** — 자이로 의존도가 높다는 결론 자체는 그대로입니다.

1. **부팅 시** — 포크 호밍이 끝난 뒤 300샘플(3초) 평균. 이 구간에 로봇이 움직이면 바이어스가 오염되어 한쪽으로 계속 틀어집니다
2. **주행 중** — 게이트 **두 개를 모두** 통과할 때만 `bias = 0.999*bias + 0.001*raw`
   - `drive_percent == 0`이 1초 이상 유지 (차량이 car-like이므로 구동 명령이 0이면 조향각과 무관하게 요레이트가 0)
   - **자이로 자체가 정지로 읽힘** — `|raw - bias| < 2 dps`

두 번째 게이트가 없으면 벤치에서 조용히 망가집니다. `s_drive_idle`은 `true`로 시작해 UART 명령이 와야 바뀌므로, 명령이 없는 벤치 리그에서는 영원히 "정지 중"이 되고 필터가 **실제 회전을 바이어스로 흡수**합니다. `alpha=0.001` @ 100Hz는 시정수 10초라, 손으로 90°씩 네 번 돌린 시험이 54/22/22/7도로 감쇠해 읽혔습니다. 계수를 낮게 잡은 것만으로는 부족합니다.

증상이 헷갈리는 이유는 **감쇠량이 회전에 걸린 시간에 비례**한다는 점입니다. 빨리 돌리면 덜 먹히므로 스케일 오차처럼 보이지만, 감도 상수로는 절대 고쳐지지 않습니다(모든 구간이 같은 비율로 바뀔 뿐입니다).

### 실패 시 동작

IMU나 USB 호스트가 없어도 주행과 포크는 그대로 동작합니다. `WHO_AM_I` 불일치나 USB 미연결은 로그를 남기고 지나갑니다. USB 링버퍼가 차면 프레임을 통째로 버리고 `dropped`만 올립니다 — 제어 루프는 절대 텔레메트리를 기다리지 않습니다.

## 안전 동작

- 부팅 시 DC 모터 정지 및 **서보 중앙 복귀**
  - 중앙 각도는 `TELEOP_STEERING_CENTER_CDEG`에서 유도한다(현재 **90°**). 종전 이 문서가
    "100도"라고 적고 있었는데, 조향 중립이 10000 → 9600 → 9400 → **9000**으로 세 번
    바뀌는 동안 펌웨어 상수만 안 따라온 상태였다(2026-08-06 수정, S15P11A304-203).
    **재플래시해야 반영된다.**
- 유효 명령이 500ms 동안 없으면 즉시 정지 및 중앙 복귀
- 모터 또는 서보 제어 오류 시 정지 및 중앙 복귀
- 지게차 전진은 실제 DC 전기 방향 `DC_MOTOR_DIRECTION_REVERSE`에 매핑

### 🔴 부팅 시 포크가 자동으로 움직인다

`STEPPER_MOTOR_STARTUP_HOME_ENABLED`가 **1**이라 전원을 넣으면 호밍이 돈다.

```
전원 인가 → 10초 카운트다운(경고 로그) → 하한 리밋까지 하강
         → 리밋 감지 → 500ms 대기 → 1600스텝 상승(백오프)
```

⚠️ **포크 아래에 손·화물·파렛트를 두지 말 것.** 10초 카운트다운은 치우라고 있는
시간이고, 로그에 `keep power cutoff ready`가 같이 찍힌다.

⚠️ **호밍이 실패하면 `ESP_ERROR_CHECK`가 MCU를 abort(재부팅)시킨다.** 리밋 스위치가
눌린 채 고장나면 **부팅 → 호밍 실패 → 재부팅 루프**가 된다. 그때는
`STEPPER_MOTOR_STARTUP_HOME_ENABLED`를 0으로 두고 플래시해 원인부터 본다.

## 빌드 및 플래시

```bash
. ~/.espressif/v5.5.5/esp-idf/export.sh
idf.py set-target esp32s3
idf.py build
idf.py -p /dev/ttyACM0 flash monitor
```

실제 포트에 맞게 변경합니다. 최초 실차 시험은 모터 전원을 분리한 UART 시험부터 시작한 뒤, 바퀴를 지면에서 띄워 방향과 안전 정지를 확인합니다.

## IMU 검증 순서

순서대로 진행하고 각 단계를 통과한 뒤 다음으로 갑니다. EKF를 먼저 붙이고 디버깅하면 원인을 찾을 수 없습니다.

| 단계 | 확인 | 통과 기준 |
|---|---|---|
| 0 SPI | `idf.py monitor` | `WHO_AM_I 0x70/0x71/0x73`. 실패 시 배선·CS 극성·데이터 클럭 4MHz |
| 0.5 링크 | `cat /dev/ttyACM0` | `@IMU,...*CRC` 줄이 흐름 (로그와 섞여도 프레임은 온전) |
| 1 부호 | `ros2 topic echo /imu/data --field angular_velocity.z` | 위에서 봤을 때 반시계 = 양수 (REP-103) |
| 2 바이어스 | `ros2 topic hz /imu/data` | 100Hz 근처, 정지 시 ±0.005 rad/s 이내 |
| 3 스케일 | 제자리 360° 회전 후 적분 | 6.283 rad ±5% (6.0~6.6) |

Jetson 측 절차는 [`ros2_ws/src/forklift_teleop/README.md`](../../../ros2_ws/src/forklift_teleop/README.md)를 참고합니다.

## 무부하 통합 시나리오 시연

S15P11A304-100 무인 이동·운반 MVP는 차량을 안정적인 받침대에 올려 구동 바퀴를 공중에 띄운 무부하 상태에서 검증한다.

검증 순서는 다음과 같다.

1. 전진 명령에 따라 DC 구동 바퀴가 전진 방향으로 회전한다.
2. 정지 명령 후 바퀴가 완전히 정지한다.
3. 차량 정지 후 포크가 상승한다.
4. 포크 상태가 `RUNNING`에서 `DONE`으로 전환된다.
5. 시연 후 포크를 하단 리밋까지 내리고 자동 백오프 상태로 복귀한다.

공중 부양 상태에서는 차체와 LiDAR가 이동하지 않으므로 RF2O `/odom`이 전진 거리를 생성하지 않는다. 따라서 이 시연에는 Nav2, AMCL 및 LiDAR odometry를 사용하지 않는다. 공중 부양 상태에서 Nav2를 실행하면 progress checker의 `Failed to make progress`로 중단되는 것이 정상이다.

### 안전 조건

- 차량을 흔들리지 않는 받침대에 고정한다.
- 구동 바퀴, 포크, 체인 및 스테퍼 모터 주변에서 사람을 물린다.
- 포크에는 적재물을 올리지 않는다.
- 비상 전원 차단과 `STOP` 명령을 준비한다.
- 모든 터미널에서 `ROS_DOMAIN_ID=100`을 사용한다.

### 터미널 1: UART 브리지

```bash
export ROS_DOMAIN_ID=100
source /opt/ros/humble/setup.bash
source ~/S15P11A304/ros2_ws/install/setup.bash

ros2 run forklift_teleop uart_teleop_bridge --ros-args \
  --params-file ~/S15P11A304/ros2_ws/src/forklift_teleop/config/teleop.yaml \
  --log-level uart_teleop_bridge:=debug
```

`ACK sequence=... status=OK`가 계속 수신되는지 확인한다.

### 터미널 2: 포크 상태 감시

```bash
export ROS_DOMAIN_ID=100
source /opt/ros/humble/setup.bash
source ~/S15P11A304/ros2_ws/install/setup.bash

ros2 topic echo /fork/status
```

### 터미널 3: 자동 시연

```bash
export ROS_DOMAIN_ID=100
source /opt/ros/humble/setup.bash
source ~/S15P11A304/ros2_ws/install/setup.bash

echo "[1/3] Simulated forward travel"

timeout 3 ros2 topic pub -r 20 \
  /cmd_vel geometry_msgs/msg/Twist \
  "{linear: {x: 0.10}, angular: {z: 0.0}}"

echo "[2/3] Drive stop"

ros2 topic pub --once \
  /cmd_vel geometry_msgs/msg/Twist \
  "{linear: {x: 0.0}, angular: {z: 0.0}}"

sleep 1

echo "[3/3] Fork lift"

ros2 topic pub --once \
  /fork/command std_msgs/msg/String \
  "{data: UP}"
```

### 비상 정지

```bash
ros2 topic pub --once \
  /cmd_vel geometry_msgs/msg/Twist \
  "{linear: {x: 0.0}, angular: {z: 0.0}}"

ros2 topic pub --once \
  /fork/command std_msgs/msg/String \
  "{data: STOP}"
```

### 시연 종료 후 포크 호밍·초기화

포크만 하한 원점으로 보낼 때는 `HOME`을 사용한다. 이 명령은 정해진 이동량이
아니라 하한 홈 스위치가 눌릴 때까지 계속 내려간다.

```bash
ros2 topic pub --once \
  /fork/command std_msgs/msg/String \
  "{data: HOME}"
```

운행 시작 전 조향까지 정면으로 맞추려면 `INITIALIZE`를 보낸다. 완료 상태가 올
때까지 ROS2 브리지는 주행 명령을 0·중앙 조향으로 유지한다.

```bash
ros2 topic pub --once \
  /fork/command std_msgs/msg/String \
  "{data: INITIALIZE}"
```

하단 리밋 접촉 후 정지하고, 500ms 뒤 조금 상승해 스위치가 해제된 상태에서 `DONE`이 나오면 초기화 완료다.

### 검증 결과와 범위

S15P11A304-100에서 무부하 공중 부양 상태의 `전진 구동 → 정지 → 포크 상승` 자동 순차 동작과 포크의 `RUNNING → DONE` 상태 전환을 실차 하드웨어로 확인했다.

본 시험은 차체 이동을 제외한 무부하 벤치 통합 검증이다. 실제 지면에서의 위치 이동, AMCL 수렴 및 Nav2 경로 추종은 후속 실차 검증 범위다.

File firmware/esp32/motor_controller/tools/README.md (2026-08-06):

# 브링업 검증 도구

USB 상행 링크(`/dev/ttyACM0`)로 붙어 프레임을 직접 뜯어보는 도구들입니다.
ROS2를 띄우지 않고 펌웨어만 확인할 때 씁니다.

프레임 파서는 `ros2_ws/src/forklift_teleop`의 `sensor_protocol.py`를 그대로
가져다 씁니다 — 브리지가 쓰는 것과 같은 코드로 검증해야 의미가 있습니다.

> **주의**: 포트를 여는 순간 ESP32가 리셋되고 **포크 호밍이 한 번 돕니다.**
> 포크 주변을 비우고 실행하세요. 그래서 IMU·ToF 데이터는 부팅 후 20초쯤
> 지나야 나오기 시작합니다.

## `tof_probe.py`

ToF 두 개와 IMU를 한 번에 확인합니다.

```bash
python3 tools/tof_probe.py [초]      # 기본 60초
```

- I2C1 스캔 로그, 주소 배정 결과, 펌웨어 업로드 성공 여부
- 센서별 `@TOF` 수신율·결번, **유효 존만의 거리**와 상태 분포
- `@IMU` 무회귀 확인 — ToF를 얹어도 100Hz·결번 0이 유지되는지
- **ESP32 재부팅 감지** — 시퀀스가 역행하면 구간을 나눠 보고합니다

프레임이 안 나올 때 로그에서 볼 순서:

| 로그 | 원인 |
|---|---|
| `answered neither 0x29 nor 0x2A` | 배선, `SPI_I2C_N` |
| `address did not stick` | **`SPI_I2C_N` 플로팅** — 가장 흔했던 원인 |
| `sensor init failed` | 84KB 펌웨어 업로드 실패, 풀업 |
| `is being polled` | INT 배선 (동작은 하되 지터 증가) |

## `tof_mask_learn.py`

포크·섀시를 항상 보는 존을 찾아 마스크 목록을 출력합니다. ROS2를 띄운 상태에서:

```bash
python3 tools/tof_mask_learn.py --topic /tof/left/points --seconds 10
```

자기 가림은 **거리로 못 거릅니다** — 포크는 고정 거리라 멀쩡한 장애물처럼 보입니다.
구분되는 건 **움직이지 않는다**는 점이라, 앞을 비운 채 관찰해 계속 같은 짧은 값을
내는 존을 찾습니다.

**포크는 travel 높이로 두고** 학습하세요. 리프트를 올리면 포크가 시야에서 빠지므로
높은 상태로 학습하면 주행 중에 놓칩니다.

출력을 `sensors.yaml`의 `tof_masked_zones_left`/`_right`에 붙여넣되, 가까운 벽을
잘못 잡은 것은 아닌지 눈으로 확인하세요.

## `gyro_scale_check.py`

자이로 스케일을 90도씩 네 번 끊어 돌려 검증합니다.

```bash
python3 tools/gyro_scale_check.py
```

종이에 십자선을 긋고 보드 한 변을 맞춘 뒤, 다음 선에 맞을 때까지 돌리면
정확히 90도입니다. **속도는 상관없습니다** — 적분은 속도 프로파일과 무관하고,
90도를 1초보다 빠르게만 돌리지 않으면 ±250 dps 포화도 피합니다.

감도는 `main/config.h`에서 직접 읽습니다. 도구에 상수를 복사해 두면 펌웨어와
어긋났을 때 조용히 배율이 틀어집니다.

**구간 편차가 크면 스케일 문제가 아닙니다.** 감도는 곱셈 상수라 네 구간을 같은
비율로 바꿉니다. 구간이 점점 줄어들면 바이어스 추적기가 회전을 흡수하는
것이고, 그건 `task_imu.c`의 정지 판정 게이트를 봐야 합니다.

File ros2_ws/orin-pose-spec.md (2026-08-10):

# 오린카 좌표 전송 명세 (C팀용)

세트장이 완성되어 좌표계가 확정됐다. 이 문서 하나만 보고 구현하면 된다.
토픽 전체 규격은 [vehicle-mqtt-spec.md](vehicle-mqtt-spec.md),
관제(백엔드) 쪽 규격은 [backend-mqtt-guide.md](backend-mqtt-guide.md) 를 본다.
**이 문서와 백엔드 문서의 필드·상태값은 서로 맞춰져 있다.** 한쪽만 고치지 말 것.

---

## 0. 세 줄 요약

1. 브로커 `i15a304.p.ssafy.io:8883` (TLS, 아이디/비번 필요)
2. 토픽 `fast/v1/vehicle/fk01/telemetry` 에 **10 Hz** 로 발행 (+ `event`, `arrived` — 6장)
3. 좌표는 **내가 잰 실물 m × 10** (MQTT 는 시뮬 좌표계). 원점은 창고 왼쪽 아래

---

## 1. 브로커 접속

| 항목 | 값 |
|---|---|
| 호스트 | `i15a304.p.ssafy.io` (3.38.178.143) |
| 포트 | **8883** — TLS 전용. 1883 은 닫혀 있다 |
| 인증 | 아이디/비번 (F 팀에 문의) |
| 인증서 | 자체 서명 CA `FAST-MQTT-CA`. **CN 이 호스트명이 아니라 IP** 라서 시스템 CA 로는 검증이 실패한다 |
| QoS | telemetry 는 0 (최신값이 중요하지 재전송은 무의미) |

인증서 검증은 둘 중 하나로 한다.

- **권장** — F 팀이 뽑아 둔 CA 파일(`fast-mqtt-ca.crt`)을 받아 지정한다
- **임시** — 검증을 생략한다 (개발 중에만. 도청·위장에 취약)

```python
import ssl, json, time
import paho.mqtt.client as mqtt

c = mqtt.Client(client_id="fk01")
c.username_pw_set("아이디", "비번")

c.tls_set(ca_certs="/path/to/fast-mqtt-ca.crt")   # 권장
# c.tls_set(cert_reqs=ssl.CERT_NONE)              # 임시 (검증 생략)
# c.tls_insecure_set(True)

c.connect("i15a304.p.ssafy.io", 8883, keepalive=30)
c.loop_start()
```

---

## 2. 좌표계 ← 가장 중요

**MQTT 위의 모든 좌표는 시뮬레이션 좌표계다.** 창고는 20 × 30 이고,
실물 세트장은 그 1/10 인 2 × 3 m 다. 변환은 **오린카가 한다.**

```
    보낼 때   내가 잰 실물 m   × 10  →  MQTT
    받을 때   MQTT 좌표        ÷ 10  →  내가 갈 실물 m
```

예) 세트장에서 (1.55, 0.40) m 에 있으면 → `{"x": 15.5, "y": 4.0}` 로 발행.
관제가 `{"x": 17.0, "y": 5.0}` 을 주면 → 실제로는 (1.70, 0.50) m 로 간다.

```
        y
        ▲
   30.0 │  ┌─────────────────┐      MQTT 좌표계 (시뮬)
        │  │                 │      실물 세트장은 이것의 1/10
        │  │   창고           │      → 2.0 x 3.0 m
        │  └─────────────────┘
      0 └────────────────────▶ x
        0                  20.0
```

| 항목 | 값 |
|---|---|
| 원점 (0, 0) | 창고 **왼쪽 아래 모서리** (맵 이미지의 좌하단) |
| x 축 | 오른쪽이 + , 범위 **0 ~ 20.0** (실물 0 ~ 2.0 m) |
| y 축 | 위쪽이 + , 범위 **0 ~ 30.0** (실물 0 ~ 3.0 m) |
| yaw | +x 가 0, **반시계가 +**, **라디안** (−π ~ +π). **변환하지 않는다** |
| 기준점 | 차체의 **base_link** — **전륜 구동축** 중심 |
| forkHeight | 이것도 **×10** 해서 보낸다 (실물 0.02 m → `0.2`) |

`yaw` 는 각도라 축척과 무관하다. 그대로 보낸다.

> ⚠️ **2026-08-07 정정: 기준점은 전륜 구동축이다.** 이 문서는 "뒷바퀴 축" 이라고
> 적고 있었는데 오기였다. 실물 코드와 모든 static TF 가 전륜 구동축 기준이고,
> `ros2_ws/README.md` 와 `docs/센서-측정-칼리브레이션.md` §1 도 그렇게 적고 있다.
>
> 이 기준이 어긋나면 **축거 0.144 m 만큼 밀리고, 회전할 때마다 어긋남의 방향이
> 바뀌어** "가끔 밀린다" 로만 보인다 -- 증상으로 원인을 찾기 어렵다. 후륜(조향)축은
> `x = -0.144`, footprint 뒤끝은 `-0.245` 라 조향축 뒤로 0.101 m 가 더 나온다.
>
> 이 문서를 근거로 만든 것이 있으면 함께 확인할 것.

### 주요 지점 (MQTT 좌표 / 실물 m)

| 지점 | MQTT x, y | 실물 m |
|---|---|---|
| 입고 바이 | 17.0, 5.0 | 1.70, 0.50 |
| A랙 접근점 | 5.0, 9.3 ~ 23.8 | 0.50, 0.93 ~ 2.38 |
| A랙 적재점 | 0.95, 9.3 ~ 23.8 | 0.095, 0.93 ~ 2.38 |
| B랙 접근점 | 14.5, 9.3 ~ 23.8 | 1.45, 0.93 ~ 2.38 |
| B랙 적재점 | 10.2, 9.3 ~ 23.8 | 1.02, 0.93 ~ 2.38 |
| 순환로 | x = 5.0 / 15.5 | 0.50 / 1.55 |

### 차량 제원 (실물)

| 항목 | 실물 | 시뮬(×10) |
|---|---|---|
| 차체 | 0.380 × 0.190 m | 3.8 × 1.9 |
| 축거 | 0.140 m | 1.4 |
| 최대 조향 | 60° | 60° |
| 최소 회전반경 | 0.081 m | 0.81 |
| 통로 폭 | 0.820 m | 8.2 |

---

## 3. 발행 — `fast/v1/vehicle/fk01/telemetry`

**10 Hz**, QoS 0.

```json
{
  "vehicleId": "fk01",
  "ts": 1785936000123,
  "pose":     {"x": 17.0, "y": 5.0, "yaw": 0.0},
  "velocity": {"linear": 1.2, "angular": 0.05},
  "forkHeight": 0.2,
  "loaded": false,
  "cargoId": null,
  "cargo": null,
  "state": "IDLE",
  "taskId": null,
  "battery": 87.5
}
```

| 필드 | 형 | 설명 |
|---|---|---|
| `vehicleId` | string | 고정 `"fk01"` |
| `ts` | int | 유닉스 시각 **밀리초** |
| `pose.x` `pose.y` | float | **시뮬 좌표** = 실물 m × 10. 소수점 2자리면 실물 mm 정밀도 |
| `pose.yaw` | float | **라디안**, −π ~ +π |
| `velocity.linear` | float | m/s **× 10**. 후진은 음수 |
| `velocity.angular` | float | rad/s. 반시계가 + |
| `forkHeight` | float | 실물 m **× 10**. 바닥이 0 |
| `loaded` | bool | 화물을 들고 있는가 |
| `cargoId` | string \| null | 없으면 null |
| `cargo` | object \| null | 싣고 있는 화물의 크기. 미소지 시 `null`. `{"id","w","d","h"}` — 크기도 **×10** |
| `state` | string | 아래 표 |
| `taskId` | string \| null | 수행 중인 task 의 id. 없으면 null |
| `battery` | float | 0~100 |

### `state` 값

| 값 | 뜻 | 언제 |
|---|---|---|
| `IDLE` | 정지, 명령 대기 | |
| `MOVING` | 주행 중 | |
| **`LOADING`** | **화물을 받는 절차 중** | 입고 바이에 정렬·진입·들어올리기까지 전 구간 |
| **`UNLOADING`** | **화물을 내리는 절차 중** | 랙 정렬·진입·내려놓기·후진까지 전 구간 |
| `LIFTING` / `LOWERING` | 포크만 상승 / 하강 | 위 절차 밖에서 포크만 움직일 때 |
| `HOLDING` | 관제가 멈추라고 해서 멈춤 | `control` 로 HOLD 수신 |
| `ESTOPPED` | 비상정지 | `control` 로 ESTOP 수신 |
| `ERROR` | 고장 | |

`LOADING` / `UNLOADING` 은 **포크가 안 움직이는 구간까지 포함**합니다. 관제
화면이 "적재 중 / 하역 중" 을 표시하는 데 씁니다. 시뮬 차량도 같은 값을
쓰므로, 실물이 이 값을 보내면 관제는 시뮬·실물을 구분 없이 다룰 수 있습니다.

pose 를 아직 못 구하면 (AMCL 미수렴 등) **그 주기는 발행하지 않는다.**
`null` 이나 `0,0` 을 보내면 관제 화면에서 차량이 원점으로 순간이동한다.

---

## 4. 최소 구현 예제

```python
import json, math, ssl, time
import paho.mqtt.client as mqtt

BROKER, PORT = "i15a304.p.ssafy.io", 8883
TOPIC = "fast/v1/vehicle/fk01/telemetry"

c = mqtt.Client(client_id="fk01")
c.username_pw_set("아이디", "비번")
c.tls_set(cert_reqs=ssl.CERT_NONE)      # CA 파일을 받으면 ca_certs= 로 바꿀 것
c.tls_insecure_set(True)
c.connect(BROKER, PORT, keepalive=30)
c.loop_start()

while True:
    x, y, yaw = read_pose()             # AMCL /amcl_pose 등에서 (실물 m, rad)
    if x is None:
        time.sleep(0.1)                 # 위치를 모르면 보내지 않는다
        continue

    K = 10.0                            # 실물 m -> MQTT(시뮬) 좌표
    c.publish(TOPIC, json.dumps({
        "vehicleId": "fk01",
        "ts": int(time.time() * 1000),
        "pose": {"x": round(x * K, 3), "y": round(y * K, 3),
                 "yaw": round(math.atan2(math.sin(yaw), math.cos(yaw)), 4)},
        "velocity": {"linear": round(v * K, 3), "angular": round(w, 3)},
        "forkHeight": round(fork * K, 3),
        "loaded": bool(loaded),
        "cargoId": cargo_id,
        "state": state,
        "taskId": task_id,
        "battery": battery,
    }), qos=0)

    time.sleep(0.1)                     # 10 Hz
```

ROS2 노드로 만든다면 `/amcl_pose` 와 `/odom` 을 구독해 위 값을 채우면 된다.

목표를 받을 때는 반대로 나눈다.

```python
def on_task(client, userdata, msg):
    t = json.loads(msg.payload)
    gx, gy = t["x"] / 10.0, t["y"] / 10.0     # MQTT -> 실물 m
    yaw = t.get("yaw", 0.0)                   # 각도는 그대로
    send_goal(gx, gy, yaw)                    # Nav2 navigate_to_pose 등
```

---

## 5. 검증 — 우리 쪽에서 이렇게 확인한다

오린카가 발행을 시작하면 F 팀이 이걸 돌린다.

```bash
source /home/ubuntu/forklift_ws/nav2/config/mqtt.env
mosquitto_sub -h $MQTT_HOST -p $MQTT_PORT -u $MQTT_USER -P $MQTT_PASS \
  --cafile /home/ubuntu/forklift_ws/nav2/config/fast-mqtt-ca.crt --insecure \
  -t 'fast/v1/vehicle/fk01/telemetry' -v
```

그리고 Isaac 의 `REAL_F01` 이 세트장의 실제 위치와 같은 자리로 움직이는지 본다.

### 자가 점검 목록

- [ ] 10 Hz 로 꾸준히 나가는가 (끊기면 관제가 LOST 로 본다)
- [ ] x 가 0 ~ 20.0, y 가 0 ~ 30.0 범위 안인가 — **벗어나면 ×10 을 안 했거나 두 번 한 것**
- [ ] 세트장 한가운데(1.0, 1.5)에서 `{"x":10.0,"y":15.0}` 이 나가는가
- [ ] 차를 손으로 오른쪽으로 밀면 x 가 커지는가
- [ ] 차를 위(랙 안쪽)로 밀면 y 가 커지는가
- [ ] +x 를 향할 때 yaw ≈ 0, +y 를 향할 때 yaw ≈ +1.571 인가
- [ ] `ts` 가 밀리초인가 (초 단위면 1000배 작다)
- [ ] 위치를 모를 때 0,0 을 보내지 않는가

### 흔한 실수

| 증상 | 원인 |
|---|---|
| 원점 근처에 붙어 있다 | **×10 을 안 함**. 실물 m 을 그대로 보냄 |
| 창고 밖 멀리 있다 | ×10 을 **두 번** 했거나, mm/cm 단위로 잼 |
| 목표를 받고 창고 밖으로 나간다 | 받을 때 **÷10 을 안 함** |
| 각도만 이상하다 | yaw 를 degree 로 보냄. **라디안** |
| 좌우가 뒤집힌다 | y 축 방향 반대. 맵 좌하단이 원점 |
| 원점에서 깜빡인다 | 위치 미확정일 때 0,0 을 보냄 |

---

## 6. 다음 단계

좌표 발행이 확인되면 아래를 순서대로 붙인다.

### 6.1 추가 발행 — 사건과 도착

telemetry 만으로는 관제가 "언제 무슨 일이 있었는지" 를 놓친다.

| 토픽 | 언제 | 예시 |
|---|---|---|
| `fast/v1/vehicle/fk01/event` | 상태가 바뀔 때 | `{"ts":..., "type":"LOAD_DONE", "level":"INFO", "message":"적재 완료"}` |
| `forklift/fk01/arrived` | **입고 바이에 도착해 멈췄을 때** | `{"ts":..., "vehicleId":"fk01", "position":{"x":17.0,"y":5.0}}` |

`arrived` 는 **AI 팀의 화물 측정 트리거**다. 이게 없으면 카메라가 언제 재야
할지 모른다. 접두사가 `forklift/` 로 다른 점에 주의 (이전 합의를 유지).

반드시 보내야 하는 `event.type`: `LOAD_DONE`, `UNLOAD_DONE`,
`ESTOP_TRIGGERED`, `RESUMED`, `TASK_FAILED`, `ERROR`.

### 6.2 구독 — 목적지를 받아 움직이기

```
fast/v1/vehicle/fk01/task       QoS 1
```

**받은 좌표는 시뮬 좌표다. ÷10 해야 실제로 갈 위치(m)가 된다.**

#### 단순 이동

```json
{ "taskId": "T-0042", "ts": 1785000000000, "action": "GOTO",
  "pickup": { "x": 17.0, "y": 5.0, "yaw": 0.0 } }
```

받으면 → `(1.70, 0.50) m` 로 환산해 자기 Nav2 에 `navigate_to_pose` 를 넣는다.
경로 계획과 장애물 회피는 차량이 알아서 한다. 관제는 목적지만 준다.

> 관제는 순환로를 따라 **다음 지점을 하나씩** 보낸다. 같은 목표를 반복해서
> 보내지 않으므로, 받을 때마다 새 목표로 갈아타면 된다.

#### 랙 적재 — `PLACE_RACK`

```json
{ "taskId": "T-0043", "action": "PLACE_RACK", "cargoId": "C-0007",
  "approach":    { "x": 5.00, "y": 9.30, "yaw": 3.1416 },
  "dock":        { "x": 2.60, "y": 9.30, "yaw": 3.1416 },
  "shelfHeight": 13.25,
  "reverseDist": 2.0 }
```

모든 길이가 시뮬 값이다. ÷10 하면 실물 값이 된다.

```
1. approach (0.500, 0.930) 까지 Nav2 로 주행
2. 포크를 shelfHeight (1.325 m) 로 상승
3. approach → dock (0.260, 0.930) 까지 저속 직진    ← Nav2 를 쓰지 않는다
4. 포크 하강 (= 화물이 선반에 얹힌다)
5. reverseDist (0.20 m) 만큼 후진
6. `event` 로 UNLOAD_DONE 발행
```

**3번이 핵심이다.** dock 지점은 차체가 랙과 겹치는 자리라 Nav2 가 "경로 없음"
을 낸다. 포크를 랙 안에 넣어야 하니 당연한 일이다. 이 구간만 **저속 직진**
으로 처리한다 — 오도메트리보다 **라이다로 랙 면까지 거리를 재서 보정**하는
편이 안전하다 (“랙 면에서 X cm 남을 때까지 전진”).

절차 전 구간의 `state` 는 **`UNLOADING`** 으로 보낸다.
바이에서 화물을 받는 절차는 **`LOADING`** 이다.

### 6.3 구독 — 정지 / 재개

```
fast/v1/vehicle/fk01/control    QoS 1
fast/v1/control/all             전체 제어 (같은 페이로드)
```

```json
{ "ts": 1785000000000, "command": "HOLD" }
```

| `command` | 받으면 |
|---|---|
| **`HOLD`** | 즉시 정지(포크 높이는 유지). `state` 를 `HOLDING` 으로. **새 `task` 를 무시** |
| **`ESTOP`** | 즉시 정지. `state` 를 `ESTOPPED` 로. `event` 로 `ESTOP_TRIGGERED` 발행 |
| **`RESUME`** | 정지 해제. 이후 `task` 를 다시 받는다 |
| `CANCEL_TASK` | 현재 목표만 취소 (정지 상태로 들어가지 않음) |

관제는 **`RESUME` 을 보낸 뒤에 `task` 를 보낸다.** 순서가 보장되므로
"정지 중에는 task 무시" 로 구현해도 목표를 놓치지 않는다.

이걸 구현하면 실물도 시뮬 차량과 **똑같은 교통 규칙**을 받게 된다
(일방통행, 앞차 적재 중 대기, 바이 한 대 예약).
규격은 [vehicle-mqtt-spec.md](vehicle-mqtt-spec.md) 5·6장에 있다.

---

## 7. 아직 확인 못 한 위험

**라이다 최소 측정거리.** 통로 폭이 0.820 m 라 벽까지 10~20 cm 인데, 소형
라이다는 `range_min` 이 0.15 m 인 경우가 많다. 그러면 벽이 안 잡혀 AMCL 이
발산한다. 쓰는 라이다 모델과 `range_min` 을 알려주면 F 팀이 맵·설정을 맞춘다.

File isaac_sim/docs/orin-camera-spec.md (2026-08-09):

# 차량 카메라 영상 규격 (C팀용)

관제 화면에서 실물 지게차 시점을 보기 위한 규격. 선택 기능이고, 좌표 발행
(`orin-pose-spec.md`)이 먼저다.

---

## 토픽

```
fast/v1/vehicle/fk01/camera        JPEG 바이트 (base64 아님)   QoS 0
fast/v1/vehicle/fk01/camera/info   JSON 메타 (선택)            QoS 0
```

`retain` 은 쓰지 않는다. 지난 프레임이 되살아나면 관제가 옛 화면을 보게 된다.

## 권장값

| 항목 | 값 | 이유 |
|---|---|---|
| 해상도 | **320 x 240** | MQTT 는 영상용이 아니다. 크면 브로커가 버겁다 |
| 프레임률 | **5 fps** | 관제 확인용으론 충분 |
| JPEG 품질 | 60~70 | 장당 15~30 KB |
| 대역폭 | 약 150 KB/s | 이 정도면 무리 없다 |

더 크게·부드럽게 필요하면 MQTT 말고 **별도 스트리밍**(RTSP → MediaMTX)을
쓰는 게 맞다. 시뮬 화면은 그 방식으로 내보내고 있다.

## 페이로드

**`camera`** — JPEG 원본 바이트를 그대로 싣는다. MQTT 는 바이너리를 지원하니
base64 로 감싸지 않는다 (감싸면 33% 커진다).

**`camera/info`** — 바뀔 때만, 또는 1초에 한 번.

```json
{ "vehicleId": "fk01", "ts": 1786100000000,
  "w": 320, "h": 240, "fps": 5, "format": "jpeg" }
```

## 발행 예제 (Python)

```python
import cv2, ssl, time
import paho.mqtt.client as mqtt

c = mqtt.Client(client_id="fk01-cam")
c.username_pw_set("아이디", "비번")
c.tls_set(ca_certs="fast-mqtt-ca.crt")
c.tls_insecure_set(True)           # 인증서 CN 이 IP 라서
c.connect("i15a304.p.ssafy.io", 8883, 30)
c.loop_start()

cap = cv2.VideoCapture(0)
TOPIC = "fast/v1/vehicle/fk01/camera"
while True:
    ok, frame = cap.read()
    if not ok:
        time.sleep(0.1); continue
    frame = cv2.resize(frame, (320, 240))
    ok, buf = cv2.imencode(".jpg", frame,
                           [cv2.IMWRITE_JPEG_QUALITY, 65])
    if ok:
        c.publish(TOPIC, buf.tobytes(), qos=0, retain=False)
    time.sleep(0.2)                # 5 fps
```

ROS2 노드로 만든다면 `/camera/image_raw` 를 구독해
`cv_bridge` 로 변환한 뒤 같은 방식으로 발행하면 된다.

## 확인

F 팀에서 이걸로 봅니다.

```bash
source nav2/config/mqtt.env
python3 nav2/scripts/view_camera.py fk01
```

창이 뜨고 영상이 보이면 성공. 수신 통계(fps, KB/s)도 5초마다 찍힌다.

## 주의

- **부하**: 브로커는 팀 전체가 같이 쓴다. 해상도·fps 를 올리기 전에 알려달라
- **전송 실패 시**: QoS 0 이라 유실돼도 재전송하지 않는다. 그게 맞다 (옛 프레임은 쓸모없다)
- **필수 아님**: 좌표·상태 발행이 먼저다. 카메라는 여유가 생기면 붙이면 된다

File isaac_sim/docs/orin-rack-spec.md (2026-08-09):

# 오린카 랙 좌표 명세 (C팀용)

랙에 화물을 놓거나 꺼낼 때 필요한 좌표와 절차. 이 문서 하나로 구현할 수 있다.
MQTT 규격은 [orin-pose-spec.md](orin-pose-spec.md) 를 본다.

기계가 읽을 파일도 같이 제공한다.

    nav2/config/rack_slots.json     프로그램용
    nav2/config/rack_slots.csv      표 (시뮬·실물 두 단위)

---

## 0. 세 줄 요약

1. 슬롯마다 **approach / dock / place** 세 좌표가 있다
2. **방향은 전부 `yaw = 3.1416` (서쪽 −x)** — A랙 B랙 똑같다
3. approach 까지만 Nav2, **approach → dock 은 저속 직진** (Nav2 로는 못 간다)

---

## 1. 좌표 단위

이 문서의 표는 **실물 미터**다. MQTT 로 오는 값은 시뮬 좌표계라
**÷10** 하면 이 표의 값이 된다.

```
MQTT  {"x": 5.00, "y": 9.30}   ÷10 →   실제로 갈 곳 (0.500, 0.930) m
```

`yaw` 는 라디안이라 **변환하지 않는다**.

---

## 2. 랙 배치

```
        y
   2.475 ┌───┐            ┌───┐        ← 랙 위쪽 끝
         │   │            │   │
         │ A │            │ B │
         │   │            │   │
   0.845 └───┘            └───┘        ← 랙 아래쪽 끝
         0.010          0.945
             0.150          1.085      ← 진입면(도킹 기준)
```

| 랙 | x 범위 (m) | y 범위 (m) | 진입면 |
|---|---|---|---|
| **A** | 0.010 ~ 0.150 | 0.845 ~ 2.475 | **0.150** (동쪽) |
| **B** | 0.945 ~ 1.085 | 0.845 ~ 2.475 | **1.085** (동쪽) |

두 랙 모두 **동쪽 면**이 진입면이다. 그래서 지게차는 언제나 **서쪽(−x)을
보고** 들어간다.

---

## 3. 방향 — 전부 `yaw = 3.1416`

```
      A랙                            B랙
  ┌────┐                        ┌────┐
  │    │ ◀━━━━━ ●               │    │ ◀━━━━━ ●
  └────┘  yaw = π               └────┘  yaw = π
  0.150  0.260   0.500          1.085  1.195   1.450
   진입면  dock  approach         진입면  dock  approach
```

approach · dock · place **세 좌표 모두 같은 방향**이다.

`±π` 는 같은 방향이므로, 각도 오차는 반드시 감싸서(wrap) 계산한다.

```python
err = math.atan2(math.sin(target - yaw), math.cos(target - yaw))
```

그냥 빼면 179° 와 −179° 가 358° 차이로 나와 차가 한 바퀴 돌려고 한다.

---

## 4. 슬롯 좌표 (실물 m)

`yaw` 는 전부 **3.1416**, 포크 높이(shelfHeight)는 전부 **0.1325 m**.

### A랙 (왼쪽 벽)

| 슬롯 | approach | dock | place |
|---|---|---|---|
| **A1** | 0.500, 0.930 | 0.260, 0.930 | 0.095, 0.930 |
| **A2** | 0.500, 1.050 | 0.260, 1.050 | 0.095, 1.050 |
| **A3** | 0.500, 1.180 | 0.260, 1.180 | 0.095, 1.180 |
| **A4** | 0.500, 1.320 | 0.260, 1.320 | 0.095, 1.320 |
| **A5** | 0.500, 1.450 | 0.260, 1.450 | 0.095, 1.450 |
| **A6** | 0.500, 1.580 | 0.260, 1.580 | 0.095, 1.580 |
| **A7** | 0.500, 1.720 | 0.260, 1.720 | 0.095, 1.720 |
| **A8** | 0.500, 1.850 | 0.260, 1.850 | 0.095, 1.850 |
| **A9** | 0.500, 1.970 | 0.260, 1.970 | 0.095, 1.970 |
| **A10** | 0.500, 2.120 | 0.260, 2.120 | 0.095, 2.120 |
| **A11** | 0.500, 2.250 | 0.260, 2.250 | 0.095, 2.250 |
| **A12** | 0.500, 2.380 | 0.260, 2.380 | 0.095, 2.380 |

### B랙 (가운데)

| 슬롯 | approach | dock | place |
|---|---|---|---|
| **B1** | 1.450, 0.930 | 1.195, 0.930 | 1.020, 0.930 |
| **B2** | 1.450, 1.050 | 1.195, 1.050 | 1.020, 1.050 |
| **B3** | 1.450, 1.180 | 1.195, 1.180 | 1.020, 1.180 |
| **B4** | 1.450, 1.320 | 1.195, 1.320 | 1.020, 1.320 |
| **B5** | 1.450, 1.450 | 1.195, 1.450 | 1.020, 1.450 |
| **B6** | 1.450, 1.580 | 1.195, 1.580 | 1.020, 1.580 |
| **B7** | 1.450, 1.720 | 1.195, 1.720 | 1.020, 1.720 |
| **B8** | 1.450, 1.850 | 1.195, 1.850 | 1.020, 1.850 |
| **B9** | 1.450, 1.970 | 1.195, 1.970 | 1.020, 1.970 |
| **B10** | 1.450, 2.120 | 1.195, 2.120 | 1.020, 2.120 |
| **B11** | 1.450, 2.250 | 1.195, 2.250 | 1.020, 2.250 |
| **B12** | 1.450, 2.380 | 1.195, 2.380 | 1.020, 2.380 |

x 는 랙마다 고정이고 y 만 슬롯별로 다르다.

---

## 5. 세 좌표의 뜻

| 좌표 | 쓰는 법 |
|---|---|
| **approach** | Nav2 `navigate_to_pose` 목표. 여기까지는 자율주행 |
| **dock** | 포크를 랙에 넣었을 때의 차량 중심. **Nav2 로는 못 간다** |
| **place** | 파레트가 놓이는 자리. 참고용 (포크를 내리면 여기 놓인다) |

**dock 은 차체가 랙과 겹치는 자리**라 Nav2 가 "경로 없음" 을 낸다.
포크를 랙 안에 넣어야 하니 당연한 일이다. 이 구간만 직접 몬다.

---

## 6. 적재 절차 (`PLACE_RACK`)

관제가 이런 지시를 보낸다 (좌표는 시뮬 단위).

```json
{ "taskId": "T-0043", "action": "PLACE_RACK", "rack": "A1", "cargoId": "C-0007",
  "approach":    { "x": 5.00, "y": 9.30, "yaw": 3.1416 },
  "dock":        { "x": 2.60, "y": 9.30, "yaw": 3.1416 },
  "shelfHeight": 1.325,
  "reverseDist": 2.0 }
```

받으면 **÷10** 해서 아래 순서로 수행한다.

```
1. approach (0.500, 0.930) 까지 Nav2 로 주행
2. yaw 를 3.1416 에 맞춘다          ← 여기가 안 맞으면 3번이 무의미
3. dock (0.260, 0.930) 까지 240 mm 저속 직진   ← Nav2 를 쓰지 않는다
4. 포크를 0.1325 m 로 올린 뒤 내린다 (화물이 선반에 얹힌다)
5. 200 mm 후진
6. event 로 UNLOAD_DONE 발행
```

절차 전 구간의 `state` 는 **`UNLOADING`** 으로 보낸다.

### 허용 오차

| 단계 | 허용 |
|---|---|
| approach 도착 | ±30 mm, ±10° |
| **dock 진입 직전 각도** | **±3°** |
| 최종 포크 위치 | ±12 mm |

240 mm 직진에 3° 틀어지면 끝에서 **12 mm** 밀린다. 그게 한계다.

### ToF 로 보정할 것

오도메트리만으로 240 mm 에 12 mm 정밀도는 빠듯하다. 앞쪽 ToF 로 랙 면까지
거리를 재며 들어가는 편이 안전하다.

```python
# 랙 면에서 남길 거리 = dock(0.260) - 진입면(0.150) = 0.110 m
while tof_front() > 0.110:
    drive_slow()
```

좌우 ToF 가 있으면 **평행 정렬**까지 된다.

```python
if abs(tof_left - tof_right) > 0.005:    # 5 mm 이상 차이
    조향 보정                              # 랙 면과 평행하게
```

---

## 7. 반출 절차 (`PICK_RACK`)

`PLACE_RACK` 의 역순이다. 포크를 선반 아래로 넣고 살짝 올려 화물을 든 뒤
후진한다. 완료 후 `event` 로 `LOAD_DONE` 을 발행한다.

절차 중 `state` 는 **`LOADING`**.

---

## 8. 입고 바이

랙과 별개로, 화물을 처음 받는 자리다.

| 항목 | 값 (실물 m) |
|---|---|
| 위치 | **1.650, 0.500** |
| 방향 | **yaw = 0** (동쪽) — 랙과 반대다 |
| 도착하면 | `forklift/fk01/arrived` 발행 → AI 가 화물을 측정 |

방향이 랙과 반대(동쪽)이니 주의한다.

---

## 9. 랙 좌표를 직접 들고 있을 필요는 없다

관제가 `task` 로 approach·dock·shelfHeight 를 **매번 보내준다.** 이 문서의
표는 **검증용**이다 — 관제가 준 값이 맞는지 대조할 때 쓴다.

`rack_slots.json` 을 읽어 자체 검증을 넣어두면 좋다.

```python
import json
SLOTS = json.load(open("rack_slots.json"))["slots"]

def check(rack, got_x, got_y):          # got_* 는 이미 ÷10 한 실물 m
    want = SLOTS[rack]["approach"]
    dx = abs(got_x - want["x"] / 10)
    dy = abs(got_y - want["y"] / 10)
    if dx > 0.02 or dy > 0.02:
        print(f"경고: {rack} 좌표가 표와 다릅니다 ({dx*1000:.0f}, {dy*1000:.0f} mm)")
```

---

## 10. 확인이 필요한 값

| 항목 | 현재 가정 | 확인 |
|---|---|---|
| 1층 선반 높이 | 0.1325 m | 실측 140 mm 라면 0.140 으로 조정 |
| 랙 길이 | 1.630 m | 실측 1.600 m 면 슬롯 y 를 다시 뽑는다 |
| 랙 폭 | 0.140 m | 진입면 위치만 맞으면 무관 |

선반 높이가 다르면 알려주면 `shelfHeight` 를 바꿔 보내겠다.

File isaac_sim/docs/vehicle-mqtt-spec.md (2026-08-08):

# 차량 MQTT 규격 (실물 지게차 구현용)

실물 지게차(오린카)가 관제와 주고받을 MQTT 메시지 규격.
**시뮬 차량도 같은 규격을 쓴다** — 관제는 실물/시뮬을 구분하지 않는다.

`docs/interface-spec.md` 의 형식을 따르고, 실물 구현에 필요한 부분만 자세히
풀었다.

---

## 0. 실물이 해야 할 일 — 3가지

| # | 무엇 | 방향 | 주기 |
|---|---|---|---|
| 1 | **내 위치를 알린다** | 발행 | 10 Hz |
| 2 | **일이 생기면 알린다** (도착·적재·하역·오류) | 발행 | 발생 시 |
| 3 | **관제 명령을 따른다** (목적지·정지) | 구독 | 수신 시 |

3번이 없으면 관제가 교통 규칙을 적용할 수 없다. 1번만 있으면 다른 차량이
피해 다니는 "움직이는 장애물" 로만 취급된다.

---

## 1. 공통 규칙

| 항목 | 값 |
|---|---|
| 브로커 | 팀 공용 (호스트·포트는 별도 공유) |
| 토픽 접두 | `fast/v1/vehicle/{vehicleId}/...` |
| vehicleId | 실물 `fk01`, 시뮬 `sim02`(SIM_F02), `sim03`(SIM_F03) |
| 페이로드 | JSON (UTF-8) |
| `ts` | epoch milliseconds (UTC) |
| 길이 | **m** |
| 각도 | **rad**, −π~π, x축 기준 반시계(CCW +) |
| Retain | 사용 안 함 (오래된 위치가 남으면 위험) |

### 좌표계 — 확정 (2026-08-05)

**MQTT 로 오가는 모든 좌표는 시뮬레이션 좌표계(20 × 30)다.**
실물 세트장은 그 1/10 인 2 × 3 m 이고, **변환은 차량(오린카)이 자기 쪽에서** 한다.

```
    보낼 때   내가 잰 실물 m   × 10  →  MQTT
    받을 때   MQTT 좌표        ÷ 10  →  내가 갈 실물 m
```

길이 단위는 전부 같은 규칙이다 — `pose`, `velocity.linear`, `forkHeight`,
`shelfHeight`, `reverseDist`, `cargo.w/d/h`. **`yaw` 만 예외**로 라디안 그대로.

관제(백엔드)와 시뮬은 아무 변환도 하지 않는다.

상세와 자가 점검 목록은 [orin-pose-spec.md](orin-pose-spec.md) 2장에 있다.

---

## 2. 발행 ① 위치 — `telemetry`

```
fast/v1/vehicle/fk01/telemetry     10 Hz     QoS 0
```

```json
{
  "vehicleId": "fk01",
  "ts": 1785000000000,
  "pose":     { "x": 15.5, "y": 4.0, "yaw": 1.5708 },
  "velocity": { "linear": 1.2, "angular": 0.03 },
  "forkHeight": 1.325,
  "loaded": true,
  "cargoId": "C-0007",
  "cargo":    { "id": "C-0007", "w": 0.75, "d": 0.91, "h": 1.11 },
  "state": "MOVING",
  "taskId": "T-0042",
  "battery": 87.5
}
```

| 필드 | 필수 | 설명 |
|---|---|---|
| `pose.x`, `pose.y` | **필수** | 지도 원점 기준(m). 이것만 있어도 교통 규칙이 동작한다 |
| `pose.yaw` | 권장 | 차량이 바라보는 방향(rad) |
| `velocity.linear` | 선택 | 전진 속도(m/s). 음수면 후진 |
| `forkHeight` | 권장 | 포크 높이(m). 바닥에서 포크 윗면까지 |
| `loaded` | **필수** | 화물을 들고 있는가 |
| `cargoId` | 권장 | 들고 있는 화물 ID (없으면 `null`) |
| `state` | 권장 | 아래 표 참고 |
| `taskId` | 권장 | 지금 수행 중인 작업 ID (없으면 `null`) |
| `battery` | 선택 | % |

`state` 값: `IDLE` · `MOVING` · `LIFTING` · `LOWERING` · `DOCKING` ·
`HOLDING` · `ESTOPPED` · `ERROR`

> **10 Hz 를 지킬 것.** 관제가 0.5초마다 판단하는데, 위치가 그보다 늦게 오면
> 앞차와의 간격 계산이 어긋난다. **2초 이상 끊기면 관제는 그 차량을 제어
> 불가로 보고 명령을 중단한다.**

---

## 3. 발행 ② 사건 — `event`

```
fast/v1/vehicle/fk01/event     발생 시     QoS 1
```

```json
{
  "vehicleId": "fk01",
  "ts": 1785000000000,
  "type": "CARGO_PLACED",
  "severity": "INFO",
  "taskId": "T-0042",
  "cargoId": "C-0007",
  "detail": "랙 A1 선반에 적재 완료"
}
```

### 반드시 보내야 하는 사건

| `type` | 언제 | `severity` |
|---|---|---|
| `TASK_COMPLETED` | 받은 작업을 끝냈을 때 | INFO |
| `TASK_FAILED` | 작업을 못 끝냈을 때 (경로 실패 등) | ERROR |
| **`CARGO_LOADED`** | **포크에 화물을 실었을 때** | INFO |
| **`CARGO_PLACED`** | **화물을 내려놓았을 때** | INFO |
| `ESTOP_TRIGGERED` | 비상정지가 걸렸을 때 | ERROR |
| `OBSTACLE_DETECTED` | 장애물로 스스로 멈췄을 때 | WARN |
| `SENSOR_FAULT` | 센서 이상 | ERROR |
| `LOW_BATTERY` | 배터리 부족 | WARN |

**`CARGO_LOADED` / `CARGO_PLACED` 가 중요하다.** 관제가 이걸 받아야
"이 차는 이제 랙으로 가야 한다 / 다시 바이로 가야 한다" 를 판단하고,
랙 재고를 갱신한다.

```json
// 적재 완료 — 포크를 올려 화물이 실린 것을 확인한 시점
{"type":"CARGO_LOADED","cargoId":"C-0007","detail":"높이 0.15 m"}

// 하역 완료 — 포크를 내려 화물이 선반에 얹힌 것을 확인한 시점
{"type":"CARGO_PLACED","cargoId":"C-0007","detail":"랙 A1"}
```

---

## 4. 발행 ③ 도착 — `arrived`

입고 바이에 도착해 멈췄을 때. AI(비전)가 이 메시지를 받아 화물 측정을
시작한다.

```
forklift/{vehicleId}/arrived     QoS 1
```

```json
{
  "vehicleId": "fk01",
  "event": "ARRIVED",
  "location": "INBOUND",
  "position": { "x": 1.70, "y": 0.50, "frameId": "map" },
  "heading": 0.0,
  "messageAt": "2026-08-05T10:30:45.304+09:00"
}
```

`location`: `INBOUND`(입고) · `OUTBOUND`(출고) · `RACK`(랙)

---

## 5. 구독 ① 목적지 — `task`

> **좌표는 시뮬 좌표계(0~20 × 0~30)로 옵니다.** 받아서 **÷10** 해야 실제로
> 갈 위치(m)가 됩니다. `shelfHeight` · `reverseDist` 같은 길이도 마찬가지입니다.
> 자세한 것은 [orin-pose-spec.md](orin-pose-spec.md) 2장을 보세요.

```
fast/v1/vehicle/fk01/task     QoS 1
```

### 5.1 단순 이동

```json
{
  "taskId": "L-0042",
  "ts": 1785000000000,
  "action": "GOTO",
  "pickup": { "x": 15.5, "y": 27.0, "yaw": 1.5708 }
}
```

**받으면**: 자기 Nav2 에 `navigate_to_pose` 로 그 좌표를 넣는다.
경로 계획과 장애물 회피는 차량이 알아서 한다. 관제는 목적지만 준다.

> 관제는 순환로를 따라 **다음 모서리를 하나씩** 보낸다. 같은 목표를 반복해서
> 보내지는 않으므로, 받을 때마다 새 목표로 갈아타면 된다.

### 5.2 랙 적재 — `PLACE_RACK`

```json
{
  "taskId": "T-0042",
  "ts": 1785000000000,
  "action": "PLACE_RACK",
  "cargoId": "C-0007",
  "approach":    { "x": 5.00, "y": 9.30, "yaw": 3.1416 },
  "dock":        { "x": 2.60, "y": 9.30, "yaw": 3.1416 },
  "shelfHeight": 1.325,
  "reverseDist": 2.0
}
```

**받으면 아래 순서로 수행한다.**

```
1. approach 까지 Nav2 로 주행
2. shelfHeight 까지 포크 상승
3. approach → dock 까지 저속 직진        ← Nav2 를 쓰지 않는다
4. 포크 하강 (= 화물이 선반에 얹힌다)
5. reverseDist 만큼 후진
6. CARGO_PLACED 이벤트 발행
```

> **3번이 핵심이다.** dock 지점은 차체가 랙과 겹치는 자리라 Nav2 가
> "경로 없음" 을 낸다. 포크를 랙 안에 넣어야 하므로 당연한 일이다.
> 그래서 이 구간만 **저속 직진(오도메트리 또는 거리센서)** 으로 처리한다.

**정밀도 주의.** 실물은 시뮬의 1/10 이라 허용 오차도 1/10 이다.

| | MQTT(시뮬) 값 | 실물로 환산 |
|---|---|---|
| 도킹 직진 거리 | 2.4 | **24 cm** |
| 포크 삽입 허용 오차 | 1.2 | **1.2 cm** |

21 cm 직진에 1.2 cm 오차는 오도메트리만으로는 빠듯하다.
**라이다로 랙 면까지 거리를 재서 보정**하는 방식을 권장한다
(“랙 면에서 X cm 남을 때까지 전진”).

### 5.3 랙에서 꺼내기 — `PICK_RACK`

`PLACE_RACK` 의 역순. 포크를 선반 아래로 넣고 살짝 올려 화물을 든 뒤 후진.

```json
{"taskId":"T-0043","action":"PICK_RACK","cargoId":"C-0007",
 "approach":{...},"dock":{...},"shelfHeight":1.325,"reverseDist":2.0}
```
완료 후 `CARGO_LOADED` 이벤트를 발행한다.

---

## 6. 구독 ② 제어 — `control`

```
fast/v1/vehicle/fk01/control     QoS 1
전체 정지는  fast/v1/control/all
```

```json
{ "ts": 1785000000000, "command": "HOLD" }
```

| `command` | 뜻 | 받으면 |
|---|---|---|
| **`HOLD`** | 교통 대기 (앞차·바이 혼잡) | 즉시 정지. **새 `task` 를 무시**한다 |
| **`RESUME`** | 대기 해제 | 정지 해제. 이후 `task` 를 다시 받는다 |
| `CANCEL_TASK` | 현재 작업 취소 | 목표만 취소 (정지 상태로 들어가지 않음) |
| `ESTOP` | 비상정지 | 즉시 정지 + `ESTOP_TRIGGERED` 발행 |

### HOLD 구현 시 주의

```
HOLD 수신 → 주행 정지 (포크는 현재 높이 유지)
         → state 를 "HOLDING" 으로 바꿔 telemetry 에 반영
         → RESUME 전까지 새 task 무시

RESUME 수신 → 정지 해제. 관제가 곧 새 task 를 보낸다
```

관제는 **RESUME 을 보낸 뒤에 task 를 보낸다.** 순서가 보장되므로
"HOLD 중 task 무시" 로 구현해도 목표를 놓치지 않는다.

---

## 7. 안전 — 반드시 지킬 것

1. **비상정지는 차량 자체 센서로 한다.** MQTT 는 네트워크 지연이 있어
   200 ms 이내 반응을 보장할 수 없다. 관제의 `HOLD` 는 "여유 있는 대기" 용이다.
2. **명령이 끊기면 스스로 멈춘다.** 마지막 명령 후 일정 시간(권장 0.5 s)
   갱신이 없으면 속도를 0 으로 한다. 관제나 네트워크가 죽어도 안전해야 한다.
3. **HOLD 와 ESTOP 을 구분한다.** HOLD 는 교통 대기(정상), ESTOP 은 비상.
   ESTOP 해제는 사람이 확인한 뒤에만.
4. **도킹 중에는 전방 감시를 유지한다.** 저속 직진 구간에서도 사람이
   들어오면 멈춰야 한다.

---

## 8. 구현 체크리스트

- [ ] 좌표계 축척 합의 (실물 기준 m 로 확정)
- [ ] `telemetry` 10 Hz 발행 (`pose`, `loaded` 필수)
- [ ] `event` 발행 — 특히 `CARGO_LOADED`, `CARGO_PLACED`
- [ ] 바이 도착 시 `arrived` 발행
- [ ] `task` 수신 → `GOTO` 를 Nav2 목표로 전달
- [ ] `task` 수신 → `PLACE_RACK` 6단계 수행
- [ ] `control` 수신 → `HOLD` / `RESUME` / `ESTOP`
- [ ] HOLD 중 `task` 무시, `state = HOLDING` 반영
- [ ] 명령 끊김 시 자동 정지 (0.5 s 워치독)
- [ ] 도킹 구간 거리 보정 (라이다 권장)

---

## 9. 테스트 방법

브로커만 있으면 관제 없이도 혼자 확인할 수 있다.

```bash
# 내가 잘 보내고 있나 (다른 터미널에서)
mosquitto_sub -t 'fast/v1/vehicle/fk01/#' -v
mosquitto_sub -t 'forklift/fk01/arrived' -v

# 관제 흉내 — 목적지 주기
mosquitto_pub -t 'fast/v1/vehicle/fk01/task' \
  -m '{"taskId":"T-1","action":"GOTO","pickup":{"x":15.5,"y":27.0,"yaw":1.5708}}'

# 관제 흉내 — 랙 적재
mosquitto_pub -t 'fast/v1/vehicle/fk01/task' -m '{
  "taskId":"T-2","action":"PLACE_RACK","cargoId":"C-0007",
  "approach":{"x":5.00,"y":9.30,"yaw":3.1416},
  "dock":{"x":2.60,"y":9.30,"yaw":3.1416},
  "shelfHeight":1.325,"reverseDist":2.0}'

# 관제 흉내 — 정지 / 해제
mosquitto_pub -t 'fast/v1/vehicle/fk01/control' -m '{"command":"HOLD"}'
mosquitto_pub -t 'fast/v1/vehicle/fk01/control' -m '{"command":"RESUME"}'
```

### 통과 기준

| # | 테스트 | 기대 |
|---|---|---|
| 1 | 가만히 두고 telemetry 관찰 | 10 Hz, `pose` 가 실제 위치와 일치 |
| 2 | `GOTO` 전송 | 그 좌표로 주행, 도착 후 `TASK_COMPLETED` |
| 3 | 주행 중 `HOLD` 전송 | 1초 이내 정지, `state = HOLDING` |
| 4 | HOLD 중 `task` 전송 | **무시** (움직이지 않음) |
| 5 | `RESUME` 후 `task` 전송 | 정상 주행 |
| 6 | `PLACE_RACK` 전송 | 6단계 수행, `CARGO_PLACED` 발행 |
| 7 | 브로커 연결 끊기 | 0.5초 내 자동 정지 |

---

## 10. 참고

| 문서 | 내용 |
|---|---|
| `docs/interface-spec.md` | 메시지 형식 원본 (전체) |
| `docs/traffic-rules-spec.md` | 관제가 어떤 규칙으로 명령을 내는지 |
| `nav2/scripts/cargo_demo.py` | 시뮬의 `place_on_rack()` — 도킹 절차 참고 구현 |
| `nav2/scripts/mqtt_bridge.py` | 시뮬 쪽 MQTT 어댑터 |

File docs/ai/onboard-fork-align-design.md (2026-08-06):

# 온보드 포크 정렬 — 타깃 선택 규칙과 오차 정의

> 확정일: 2026-07-31 · 대상: S15P11A304-143(오차 산출) → 152(제어 루프)
> 구현: `ai/src/perception/fork_align.py` · 채점: `ai/scripts/eval_entry_face.py`
> 선행 문서: `onboard-hole-label-guide.md`(라벨 규약) · `onboard-tensorrt-runbook.md`(성능)
>
> **이 문서는 설계 근거다. 실물에서 돌리는 절차는 `onboard-fork-align-runbook.md`.**

152 제어 루프를 짜기 전에 **"어느 파렛트의 어느 면으로 갈지"** 를 먼저 정한다. 이걸
정하지 않으면 프레임마다 다른 대상을 쫓아 제어가 발산한다.

## 0. 왜 이게 선결 문제인가

2026-07-31 젯슨 라이브에서 **창밖 흰 건물이 `pallet 0.50`으로 잡혔다.** 임계 0.7로
걸리긴 했지만, 진짜 창고에서는 **진짜 파렛트가 여럿 보인다** — 그때는 임계로 못 거른다.
검출기는 "파렛트가 여기 있다"까지만 말하고 "어디로 가라"는 말하지 않는다.

## 1. 파렛트 선택 — 자격과 순위를 나눈다

### 자격: 진입면이 있어야 한다

**구멍이 2개 미만인 파렛트는 score가 아무리 높아도 버린다.** 꽂을 구멍이 안 보이면
정렬할 대상이 아니다.

덤으로 오탐이 한 겹 더 걸린다. 창밖 건물·커튼 같은 도메인 밖 오탐은 그 안에 `hole`이
없다. `filter_by_geometry`(파렛트 밖 hole 제거)와 **방향이 반대이면서 맞물린다** —
한쪽은 파렛트로 구멍을 거르고, 이쪽은 구멍으로 파렛트를 거른다.

| 방어선 | 무엇을 거르나 | 근거 |
|---|---|---|
| pallet 임계 0.7 | 흰 커튼·건물 pallet 오탐 | 재현율 손실 0, 네거티브 19.5%→0% |
| `filter_by_geometry` | 파렛트 밖 hole 오탐(창문 격자) | 기하, 재현율 손실 0 |
| **자격(구멍 2개)** | **구멍 없는 파렛트 오탐** | 진입 불가능한 대상 |

### 순위: 진입면 점수를 그대로 쓴다

**선분 길이 × 최소 개구폭** 하나로 정한다. "가까운 것"·"화면 중앙" 같은 기준을 따로
만들지 않았다 — 그 점수가 이미 둘을 담고 있기 때문이다:

- 가까울수록 두 구멍의 화면 간격이 크다 (길이↑)
- 정면일수록 개구가 넓다 (폭↑) — 옆으로 비껴 있으면 폭이 먼저 깎인다

> ⚠️ **이 순위는 실측으로 검증되지 않았다.** eval 150장은 파렛트가 **전 프레임 정확히
> 1개**라(105/105) 여러 개 중 고르는 상황이 데이터에 아예 없다. 다중 파렛트 프레임을
> 찍기 전까지는 **설계 근거만 있는 규칙**이다. (검증 방법: 파렛트 2~3개를 거리·각도를
> 달리해 놓고 촬영 → 사람이 "접근 대상"을 표시 → 규칙 일치율)

### 락과 히스테리시스 — 매 프레임 argmax는 금지

점수가 붙는 상황이 실제로 흔하다(§2). 프레임마다 argmax를 다시 뽑으면 22fps 제어가
좌우로 떤다. 그래서:

- **히스테리시스**: 새 후보가 현재 타깃의 **1.3배**를 넘어야 갈아탄다. 붙는 구간
  (≤1.2배)보다 위, 실제로 갈아탈 만한 차이(eval 중앙값 1.50배)보다 아래다.
- **유예 5프레임**(≈0.23초): 검출이 깜빡여도 락을 유지한다. 놓친 프레임마다
  상태기계를 되돌리면 진입이 끊긴다.
- 프레임 간 동일 파렛트 식별은 **IoU ≥0.3**(위치 연속성). score로 잇지 않는다 —
  score는 프레임마다 흔들린다.

락 해제는 152 상태기계의 몫이다(`TargetTracker.reset()`).

## 2. 진입면 선택 — 규약을 그대로 옮기면 틀린다

라벨 가이드 §3-⑥이 런타임에 미뤄둔 문장: *"두 구멍의 중심을 이은 선분이 더 길고
개구가 넓은 쪽"*. **이걸 문자 그대로 구현하면 전부 틀린다.**

train·eval의 다면 프레임 47장(구멍 3개 이상 = 두 면이 동시에 보임)으로 채점했다:

| 후보 | train 40장 | eval 7장 | 마진 중앙값(train/eval) |
|---|---|---|---|
| 전체 쌍 · 거리만 | 0/40 | 0/7 | — |
| 전체 쌍 · 거리×평균폭 | 1/40 | 0/7 | 1.09 / 1.10 |
| 인접 쌍 · 거리×평균폭 | 33/40 | 7/7 | 1.62 / 1.09 |
| **인접 쌍 · 거리×최소폭** ← 채택 | **33/40** | **7/7** | **1.90 / 1.50** |

### ① 인접 쌍 제한이 결정적이다 (0/40 → 33/40)

앞면 구멍과 옆면 구멍을 하나씩 집으면 **선분이 가장 길어진다.** "가장 긴 쪽"을 그대로
고르면 반드시 오답이 된다. 파렛트는 볼록하고 두 면은 모서리를 공유하므로 **각 면의
구멍은 화면 x에서 겹치지 않는 구간**을 차지한다 → x로 정렬하면 같은 면끼리 이웃한다.

### ② 폭은 평균이 아니라 최소

정답률은 같고 **1등/2등 여유가 벌어진다**(중앙값 train 1.62→1.90, eval 1.09→1.50).
물리적으로도 최소가 맞다 — **포크는 둘 다 들어가야 하므로 좁은 쪽 개구가 제약**이다.

### 남은 불일치 7장은 오답이 아니다

전부 **45° 부근**이고 두 면의 개구가 112~124px 대 126~142px이다. 어느 쪽으로 들어가도
되는 프레임이라, 거기서 갈리는 건 규칙이 아니라 임의의 타이브레이크다.

⚠️ 다만 그 구간에서 **최소폭 쪽 마진 최솟값이 train 1.14 → 1.00배로 되레 붙는다.**
손해는 아니지만 **매 프레임 argmax를 그대로 쓰면 면이 뒤집힌다**는 신호다 — §1의
히스테리시스가 그래서 필요하다.

## 3. 정렬 오차 정의 — 전부 화면 단위

내부 파라미터(초점거리) 없이 계산된다. 152의 P 제어는 이 셋이면 닫힌다.

| 값 | 정의 | 부호 |
|---|---|---|
| `lateral_ratio` | (진입면 중심 x − 포크 중심선 x) / (진입면 폭의 절반) | +면 파렛트가 오른쪽 |
| `yaw_signal` | (왼쪽 구멍 폭 − 오른쪽 구멍 폭) / (두 폭의 합) | +면 오른쪽 끝이 더 멀다 |
| `approach_px` | 두 구멍 중심 간 화면 거리 | 클수록 가깝다 |

- **좌우를 비율로 재는 것**은 `load_balance`가 편하중에서 쓴 방식 그대로다 — 픽셀→mm
  캘리브레이션 없이 동작하고, 거리가 변해도 같은 임계를 쓴다.
- **요를 폭 비로 재는 것**은 라벨 규약 §3-①이 "구멍을 묶지 말라"고 한 바로 그 이유다:
  두 구멍의 실제 폭은 같으므로(35mm) 화면 폭 비가 곧 깊이 비다(w₁/w₂ = d₂/d₁).
- **포크 중심선**(`fork_center_x`)은 기본이 이미지 중앙이지만, 카메라를 차체 중심에서
  벗어나게 달았다면 반드시 넣는다. **장착 오프셋을 여기서 흡수하지 않으면 제어가 일정한
  편차를 안고 수렴한다.**

### 절대 단위가 필요하면 초점거리를 준다

`focal_px`를 주면 `yaw_deg`·`distance_mm`이 나온다. 유도:

```
w₁/w₂ = d₂/d₁                     (두 구멍의 실제 폭이 같다)
→ (d₂−d₁)/(d₂+d₁) = yaw_signal
Δd = S·sinθ,  d̄ = f·S·cosθ / span  (S = 통로 중심 간격 48.5mm)
→ tanθ = 2f/span · yaw_signal      (S가 약분돼 사라진다)
```

S가 약분되므로 **간격 실측 오차에 둔감**하다. 대신 `f`가 필요하다.

> ✅ **카메라 캘리브레이션 완료**(2026-07-31, S15P11A304-176 · `fx = 1277.65`).
> 절차는 `docs/ai/measurement/camera-calibration.md` §2. 이제 요각을 도 단위로
> 낼 수 있어 진입 판정에 `--yaw-deg-tolerance`(기본 10°)를 쓴다.
>
> ⚠️ 다만 제어 루프의 조향 입력은 여전히 `yaw_signal`(무차원)이다. 큰 각도에서
> 포화되므로 **판정에는 쓰지 않는다** — 실제로 -58.5°가 -0.07로 나와 진입이
> 허가된 적이 있다(2026-08-05).

## 4. 제어 루프 (152)

구현 `ai/src/control/fork_servo.py` · 노드 `ai/scripts/onboard_fork_align_node.py`

### 상태기계 — 순서를 강제한다

```
SEARCH ──타깃 획득──> APPROACH ──근접──> ALIGN ──진입 거리──> VERIFY ──정렬됨──> INSERT ──> DONE
   ^                     |                |                    |                  (개루프)
   └──── 소실 ───────────┴────────────────┘                    └─미정렬─> RETREAT ─> APPROACH ...
                                                                              └─ 재시도 소진 ──> ABORT
```

**뒷바퀴 조향은 제자리 회전이 안 된다.** 파렛트 코앞에서 요각을 고칠 수 없으므로
진입 전에 정렬을 끝내야 한다. 그래서 진입 거리(`INSERT_ENTER_PX`)에 도달했을 때
정렬이 안 돼 있으면 **그 자리에서 고치려 들지 않는다** — 틀어진 만큼 물러났다가
다시 접근한다.

> **2026-08-05 갱신 — 154 재시도가 구현됐다.** 설계 당시에는 "미정렬이면 즉시
> ABORT, 재접근은 154에서"였으나 지금은 `VERIFY`·`RETREAT` 두 단계가 들어가
> 같은 루프 안에서 재접근한다(기본 `--max-retries 20`, 0이면 종전처럼 즉시 ABORT).
> 45°로 돌아간 파렛트에 재접근 9회로 관통한 것이 이 경로다.
> 단계별 근거·플래그는 `docs/ai/onboard-fork-align-runbook.md` §5-2.

**INSERT는 래치된다.** 코앞에서는 구멍이 화면 밖으로 나가 검출이 끊기는 것이 정상이다.
들어가기로 했으면 눈을 감고 직진한다(153 블라인드 진입). 포크 테이퍼가 상하 자기정렬을
해주는 것이 물리적 근거다.

### 조향 부호 — 두 항의 부호가 같다

카메라 원점, 전방 +Y, 오른쪽 +X. 파렛트 면이 반시계로 θ 돌면 오른쪽 구멍이 멀어져
좁게 보인다(`yaw_signal > 0`). 그때 면의 바깥 법선은 `(+sinθ, −cosθ)` — **우리 기준
오른쪽**을 향한다. 그 법선 위로 올라가려면 오른쪽으로 돌아 들어가야 한다.
좌우 오차도 같은 방향이므로:

```
angular_z = −(k_lat · lateral_ratio + k_yaw · yaw_signal)     (ROS 관례: +z = 좌회전)
```

⚠️ **두 항을 더하면 균형점에 수렴할 뿐 둘 다 0이 되지는 않는다.** 그래서 ALIGN에서
요 게인에 `ALIGN_YAW_BOOST`(2.0)를 곱해 **요를 먼저 죽인다** — 좌우는 진입 직전까지
볼 수 있지만 요는 코앞에서 못 고치기 때문이다.

### ~~⚠️ 게인·임계는 전부 미조정 자리표시자다~~ → 대부분 실측으로 잡혔다 (2026-08-05 갱신)

설계 당시에는 실물이 없어 **부호와 구조가 맞는지 보기 위한 값**이었다. 그 뒤 08-04·08-05
실주행에서 잡았다 — 조향 중립 9000 · `INSERT_SPEED_ACTUAL` 0.110 · `INSERT_MARGIN_MM` 40 ·
요각 게이트 10° · 후진 걸음 80~120mm · 후진 조향 부호 -1.0. **근거와 측정 방법은
`ai/src/control/fork_servo.py` 의 각 상수 독스트링에 있다.**

⚠️ **08-04 값과 08-05 값을 섞지 말 것** — 08-05에 서보 펄스 범위를 고쳐(1000~2000 →
500~2500µs) 뒷바퀴 실각도가 8° → 36°가 됐다. 그 이전 게인·중립은 조향이 절반이던
시절의 값이다.

아직 자리표시자로 남은 것:

- `RETREAT_TARGET_MM` — **거리를 모를 때만**(px 모드) 쓴다. 거리를 알면 틀어진 만큼 계산한다.
- `STEER_RADIUS_MM 537` — 낡았지만 소비처 결과가 80~120mm로 잘려 **거동엔 영향이 없다**.
- `ALIGN_ENTER_PX`·`INSERT_ENTER_PX` — 카메라·해상도 종속이라 여전히 환경마다 다시 봐야 한다.
  다만 캘리브레이션(176) 이후 실제 판정은 mm 쪽(`*_ENTER_MM`)이 맡는다.

### 안전

- 어떤 경로로 끝나든(예외·Ctrl-C 포함) **0 Twist를 낸다.** 브리지 워치독(500ms)이
  잡아주긴 하지만 그 사이에 들이받기 충분하다.
- 정지 상태에서도 0 Twist를 계속 낸다 — 안 내면 워치독 정지와 의도한 정지가 구분되지
  않는다.
- **첫 실행은 `--dry-run`.** 부호가 반대면 지게차가 파렛트로 돌진한다.

### 에피소드 로깅

정렬 시도마다 `(시각, 오차, 명령)`을 남긴다. 154의 성공·실패 판정 근거로 어차피 필요한
데이터라 추가 비용이 없고, 나중에 모방학습을 붙일 여지를 닫지 않는다.

> **강화학습을 쓰지 않는 이유**: 이 문제는 "상태 → 동작"의 관계가 기하로 정확히
> 계산된다. RL은 그 관계를 모를 때 시행착오로 알아내는 방법이라 아는 것을 다시 배우는
> 셈이 된다. 학습 비용(수천 회 시도)도 스프린트에 맞지 않고, 시뮬레이터로 우회하면 이
> 프로젝트가 세 번 데인 도메인 갭을 또 만난다. 마지막 진입은 테이퍼가 물리적으로
> 해결하므로 학습할 것도 없다.

## 5. 남은 것

> 갱신 2026-08-05. 현재 값과 근거는 항상 `ai/src/control/fork_servo.py` 주석과
> `docs/ai/onboard-fork-align-runbook.md` §6 을 본다 — 이 목록은 그쪽을 가리키는 색인이다.

- [x] **게인·임계 실물 조정**(2026-08-04·08-05) — ⚠️ 08-04 값들은 조향이 명령의 1/4만
      들어가던 시절에 잡은 것이다. 08-05 펄스 범위 수정(뒷바퀴 8° → 36°) 뒤 다시 잡았다.
- [x] **카메라 내부 파라미터 캘리브레이션**(2026-07-31, S15P11A304-176 · `fx = 1277.65`)
      → 진입 판정을 도 단위로 한다(`--yaw-deg-tolerance` 10°).
- [x] **포크 중심선 `fork_center_x` 실측**(2026-08-04, `670`) — 코드 기본값에 있다.
- [x] **진입 성공·실패 판정과 재시도**(2026-08-05, S15P11A304-154) — `VERIFY`·`RETREAT`.
- [ ] ~~**다중 파렛트 프레임 촬영**~~ — **실물 파렛트가 하나뿐이라 촬영 불가이고, 데모도
      파렛트 1개라 순위 규칙이 발동하지 않는다.** 블로커에서 내렸다(2026-07-31).
      자격 규칙(구멍 없는 파렛트 탈락)은 오탐 방어로 계속 유효하다.
- [ ] **Nav2 goal 인계 지점 정의**(S15P11A304-**199**) — 관제가 standoff까지, 최종 정렬은
      이 루프. ⚠️ 192로 Nav2 MOVE 어댑터가 붙어 **둘이 `/cmd_vel` 을 동시에 잡을 수 있다.**
- [ ] **반복 성공률** — 45° 관통은 표본 1회다(154 DoD 는 "3회 중 2회"). 조향이 4.5배로
      바뀐 것이 08-05라 그 이전 통계는 전부 무효다.
- [ ] **적재 상태 검증** — 진입 깊이·미는 정도가 전부 빈 파렛트 기준이다(153).
- [ ] 직선 진입 구간 길이 — 최소 회전반경에서 산출·실측. ⚠️ `STEER_RADIUS_MM 537` 은
      낡았다(08-05 실측 실효반경 321~5627mm). 지금 거동엔 영향이 없다(후진 걸음이
      80~120mm 로 잘림) — 이 값을 다른 곳에 쓰기 전에 다시 잰다.
- [ ] 제어 주기는 **22fps(45ms)** 전제. 107fps는 벤치 최적값이다

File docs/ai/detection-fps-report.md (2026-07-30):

# 감지 정확도·FPS 측정 리포트 (FR-101-6 / S15P11A304-70)

> 두 검출 모델의 **실기기 감지 정확도와 추론 지연**을 한자리에 모은다. 배포처가 둘로 갈려
> (측정=스테이션 PC의 -m, 온보드=Jetson의 -s) KPI·측정 조건·기기가 다르므로 분리해 적는다.
> 학습 이력은 `rtmdet-training-report.md`(스테이션 계보)·`onboard-finetune-runbook.md`(온보드),
> 승격 판정 근거는 `rig-eval-map.md`(스테이션)·본 문서 §1(온보드).

## 요약

| 배포처 | 모델 | 정확도 | 실기기 지연 | KPI | 판정 |
|---|---|---|---|---|---|
| **온보드(Jetson)** | RTMDet-s @640 FP16 (ep116, pallet·hole) | G1 hole 99.5% · G2 pallet 100% · G3 오탐 0% | 엔진 10.18ms / **종단 44.96ms(22fps)** | ≤100ms(≥10fps) | **통과** |
| **스테이션(PC)** | RTMDet-m @800 (exp8, box·pallet) | 리그 mAP@0.5 **0.9898** / LOCO 0.767 | 서버 참고치 CPU 94ms·L40S 20.4ms (4070 실측 대기) | 도착→판정 ≤1초 | 정확도 통과, FPS 참고 |

---

## 1. 온보드 -s (Jetson Orin Nano) — 2026-07-30 실측

포크 정렬 비전. 다른 날 촬영한 독립 eval(정면·회전·오버행 105장 + 네거티브 120장)로 승격 게이트를 판정하고, 젯슨 실기기에서 지연을 쟀다.

### 감지 정확도 — 승격 게이트 (`scripts/eval_gates.py`, epoch 116)

| 게이트 | 결과 | 기준 | |
|---|---|---|---|
| G1 hole 재현율 | **99.5%** (220/221) | ≥95% | 통과 |
| G2 pallet 재현율 | **100%** (105/105) | ≥98% | 통과 |
| G3 네거티브 hole 오탐 | **0%** (0/120) | ≤2% | 통과 |

hole 닮은 어두운 틈(의자 다리·전선)이 많은 까다로운 네거티브 120장에도 0오탐. 판정은 score 0.4·IoU 0.5. best 선정 함정 주의 — config `save_best='coco/bbox_mAP_50'`가 epoch 22에서 1.0 포화돼 덜 학습된 22를 뽑았고, eval 재판정으로 116이 실제 최고임을 확인했다.

### 추론 지연 — G4 (`scripts/onboard_trt_bench.py`)

| 구간 | 지연 | FPS |
|---|---|---|
| 엔진 단독 (trtexec, GPU Compute) | **10.18ms** | 97.8 |
| **종단** (전처리+추론+후처리, `TrtDetector`) | **44.96ms** (p99 45.44) | **22.2** |

- 종단 44.96ms 중 전처리(letterbox·정규화·회전)가 ~35ms(젯슨 CPU numpy). 필요 시 전처리 GPU 이관으로 단축.
- **측정 조건**: TensorRT 10.3 FP16 · 전력 모드 MAXN_SUPER · 팀원 5GB 점유 경합 중 · warmUp 후 200회. 경합 상태의 값이라 한가할 때 재면 같거나 빠르다.
- 검출 3.0개/프레임(pallet 1 + hole 2)이 eval 라벨과 일치 — 런타임 관통 확인.
- ⚠️ **107fps는 벤치 최적값이지 운용값이 아니다.** 152 정렬 루프는 종단 **22fps**를 전제로 짠다. 상세 `onboard-tensorrt-runbook.md` §5.

엔진 `~/trt_test/onboard_s640_ep116_fp16.engine`(23MB), 재빌드 소스 `ai/models/onboard_s_2class/end2end_s640_ep116.onnx`(INT32 수정본).

---

## 2. 스테이션 -m (측정 PC) — exp8

박스·파렛트 측정. 정확도는 실물 리그 평가셋으로 판정(상세 `rig-eval-map.md`), FPS는 서버 참고치.

### 감지 정확도

| 평가셋 | mAP@0.5 | box | pallet |
|---|---|---|---|
| **리그 평가셋(독립 라벨)** | **0.9898** | 0.9795 | 1.0000 |
| LOCO val | 0.767 | — | — |

리그 평가셋이 데모 도메인(검은 플라스틱 파렛트) 판정 무대다. 치수 KPI(미니어처 오차 평균 0.66mm ≤ 4mm)와 편하중·전복 판정도 이 모델로 검증됐다.

### 추론 지연 (참고치 — 스테이션 4070 실측 대기)

| 경로 | 지연 |
|---|---|
| onnxruntime CPU (GPU서버, provider 미설치) | 94.0ms/frame |
| torch 전체 파이프라인 L40S GPU | 20.4ms/frame |

스테이션 KPI는 "박스 도착→판정 ≤1초(1000ms)"라 최악값 CPU 94ms도 10배 이상 여유. 단 L40S≠4070·서버≠스테이션이라 참고치이며, **스테이션 4070에서 onnxruntime-GPU로 재측정 권장**. 1초에 근접하면 640 재export로 폴백 가능.

---

## 부기 — 측정 조건이 결과를 좌우한다

- 온보드 종단 44.96ms는 **경합 중** 값이다. 젯슨은 8GB 공유 메모리라 팀원 프로세스가 상시 5GB를 쓴다. 재측정은 전력 모드·경합·전처리 포함 여부를 함께 기록해야 비교 가능하다.
- 스테이션 FPS는 아직 **실기기(4070) 미측정**이다 — 정확도(mAP)는 확정, FPS는 참고치 상태다. 이 항목은 스테이션 데모 셋업이 서면 마저 잰다.

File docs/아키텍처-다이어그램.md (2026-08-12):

# 화물 운송 관리 및 디지털 트윈 시스템 — 아키텍처

작성 기준일: 2026-08-12 · 근거·표기 규칙: [아키텍처-다이어그램-명세.md](아키텍처-다이어그램-명세.md)

```mermaid
%%{init: {"flowchart": {"nodeSpacing": 34, "rankSpacing": 62, "curve": "basis", "padding": 12}}}%%
flowchart LR
  subgraph GA["그룹 A — 클라우드 / 플랫폼 · AWS EC2 i15a304.p.ssafy.io"]
    direction TB
    F1["`**1) Frontend** · :3000
    Next.js 16.2.6 · React 19
    TypeScript 5.7.3 · Tailwind CSS 4
    shadcn/ui · STOMP over SockJS
    @nvidia/ov-web-rtc 6.6`"]
    B2["`**2) Backend** · :8080
    Java 21 · Spring Boot 3.3.4
    MyBatis 3.0.3 · REST API
    WebSocket STOMP
    Spring Integration MQTT
    Eclipse Paho 1.2.5`"]
    D3[("`**3) Database**
    MySQL 8.0`")]
    M4["`**4) Messaging** · :8883
    Eclipse Mosquitto 2
    MQTT over TLS
    allow_anonymous false`"]
    SR["`**Streaming Relay**
    MediaMTX
    RTSP 입력 :8554
    WebRTC 재생 :8889 · ICE :8189`"]
  end

  subgraph GB["그룹 B — 측정 스테이션 · 전용 PC"]
    S5["`**5) Station Measurement**
    Logitech BRIO 100
    USB 1920x1080
    TF-Nova 거리계 · 시리얼
    FoV 14도
    RTMDet-m + ONNX Runtime
    box·pallet 2클래스
    OpenCV
    화물 치수 · 전복 위험
    편하중 측정`"]
  end

  subgraph GC["그룹 C — 실제 무인 지게차"]
    direction TB
    subgraph E8["8) Edge — Jetson Orin Nano"]
      direction LR
      J8["`JetPack 6 / L4T R36.4.7
      CUDA 12.6 · TensorRT 10.3
      USB 카메라 1280x720 · YDLIDAR X4-Pro`"]
      V6["`**6) Onboard Vision**
      RTMDet-s · TensorRT FP16
      OpenCV
      pallet·hole 2클래스
      포크 정렬 오차 산출`"]
      N7["`**7) Autonomous Driving**
      ROS 2 Humble · Nav2
      AMCL · SLAM
      robot_localization
      맵 생성 · 위치 추정
      경로 계획`"]
    end
    EM9["`**9) Embedded**
    ESP32-S3
    ESP-IDF / FreeRTOS
    I2C PCA9685 PWM
    MPU6500 IMU
    MG996R 조향 서보
    구동 모터 · 포크 리프트`"]
  end

  subgraph GD["그룹 D — 디지털 트윈 / 시뮬레이션"]
    T10["`**10) Digital Twin**
    NVIDIA Isaac Sim 5.1
    Omniverse · USD
    가상 창고
    다중 지게차 시뮬레이션
    _실행 호스트 미정_`"]
  end

  F1 <--> |"REST API"| B2
  F1 <--> |"WebSocket / STOMP"| B2
  B2 --> |"SQL"| D3
  B2 <--> |"MQTT Paho"| M4
  M4 --> |"fast/station/measure_request"| S5
  S5 --> |"POST /api/stations/measurements"| B2
  M4 <--> |"command · command-result"| E8
  E8 <--> |"UART 115200 · CRC-16 · 500ms 워치독"| EM9
  T10 --> |"RTSP :8554 ffmpeg"| SR
  SR -.-> |"WebRTC 재생 :8889"| F1
  T10 -.-> |"Omniverse WebRTC 직결"| F1
  T10 -.-> |"상태 동기화"| M4
  N7 -.-> |"cmd_vel 인계 규칙 없음"| V6

  linkStyle 0,1,2,3,4,5,7,8 stroke:#1F7A3D,stroke-width:2px
  linkStyle 6,9,11,12 stroke:#C1670A,stroke-width:2px
  linkStyle 10 stroke:#8A8F98,stroke-width:1.5px

  style GA stroke:#1B3B6F,stroke-width:3px
  style GB stroke:#0B5FA5,stroke-width:3px
  style GC stroke:#2E7D32,stroke-width:3px
  style E8 stroke:#2E7D32,stroke-width:2px,stroke-dasharray: 5 4
  style GD stroke:#12796B,stroke-width:3px
```

## 연결 검증 상태

| 선 | 뜻 |
|---|---|
| 🟩 초록 실선 | **검증 완료** — 실물에서 왕복 확인된 연결 |
| 🟧 주황 점선 | **부분 / 미검증** — 배선은 됐으나 실주행·실망 검증이 남음 |
| ⬜ 회색 점선 | **대체된 경로** — 설계상 존재하나 RTSP → MediaMTX 경로로 갈음한다 |

주황으로 표시한 것:

- **`forklift/{vehicleId}/command`** — 백엔드 → Nav2 MOVE 명령은 배선까지만 검증됐고 실주행 미검증. Jetson ↔ 브로커 연결은 지금 없어진 평문 브로커 기준으로 검증한 것이라 TLS 브로커로 재검증이 필요하다.
- **`WebRTC 재생 :8889`** — 시연 망이 UDP를 통째로 막아 ICE 협상이 끝나지 않는다. TCP 폴백(`:8189/tcp`)으로 우회한다.
- **`상태 동기화`** — 트윈 ↔ 브로커 구간 미검증.
- **`/cmd_vel` 인계 규칙 없음** — Nav2와 포크 정렬 루프가 같은 토픽을 동시에 잡을 수 있는데, 누가 언제 놓고 받는지 정해지지 않았다.

## 그리면 안 되는 연결

**Database ↔ Messaging 직결.** MySQL과 Mosquitto는 서로 모른다. MQTT로 들어온 메시지는 전부 백엔드(Spring Integration MQTT)를 거쳐 MyBatis로 DB에 반영된다. 이 화살표가 있으면 틀린 그림이다.

## 그룹 밖 — 공통

| 구분 | 구성 |
|---|---|
| **11) Infrastructure** | Docker Compose · AWS EC2 · GitLab CI/CD · systemd |
| **Development Tools** | Maven · npm · Colcon · CMake · pytest · H2 테스트 인메모리 DB · COCO 라벨 포맷 |
| **학습 전용 스택** | PyTorch · MMDetection · MMDeploy · Python 3.10 — **GPU 서버 전용이며 런타임이 아니다** |

## 이 시스템에 없는 것

그림에 들어가면 사실과 다르므로 넣지 않는다.

- **CVAT** — 라벨링은 레포 자체 도구(`ai/src/dataset/label_onboard.py`)로 했다. 경로·파일 이름에 `cvat`가 남아 있지만 이름뿐이다.
- **YOLO / Ultralytics** — 검토했으나 채택하지 않았다.
- **OV5647 CSI 카메라** — 커넥터·드라이버 문제로 USB 카메라로 교체했다.
- **강화학습 기반 포크 정렬** — 기하로 정확히 계산되는 관계라 채택하지 않았다.
- **GPU 서버의 런타임 서비스** — Mosquitto · Isaac Sim · Nav2 모두 2026-08-03에 내려갔다. GPU 서버는 학습 전용이다.
- **지게차 위의 PyTorch / MMDetection / ONNX Runtime** — 학습 스택과 스테이션 스택이다. 지게차에서 도는 것은 TensorRT뿐이다.
- **지게차 위의 Logitech BRIO / TF-Nova** — 측정 스테이션 장비다. 지게차 카메라는 1280×720 USB 카메라다.

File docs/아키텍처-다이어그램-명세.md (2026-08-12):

# 아키텍처 다이어그램 작성 명세

이 문서는 **아키텍처 다이어그램을 그리기 위한 것**이다. 블록·연결·표기만 담는다.

작성 기준일: 2026-08-12
근거: 레포 실물 대조 (`pom.xml`, `frontend/monitoring-control-system/package.json`, `docker-compose.yml`, `infra/mqtt/docker-compose.yml`, `firmware/esp32/motor_controller/main/config.h`, `ai/src/station/config.py`)

시스템은 **화물을 재는 스테이션 · 화물을 나르는 무인 지게차 · 둘을 지휘하는 클라우드 백엔드 · 현장을 비추는 디지털 트윈** 네 덩어리이고, 네 덩어리는 **REST와 MQTT 두 가지로만** 대화한다.

---

## 1. 블록

번호는 **1~11을 빠짐없이, 중복 없이** 쓴다. `Streaming Relay`와 `Development Tools`는 번호를 붙이지 않는다.

### 그룹 A — 클라우드 / 플랫폼 (AWS EC2 `i15a304.p.ssafy.io`)

| 블록 | 구성 | 역할 |
|---|---|---|
| **1) Frontend** | Next.js 16.2.6, React 19, TypeScript 5.7.3, Tailwind CSS 4, shadcn/ui, STOMP over SockJS, `@nvidia/ov-web-rtc` 6.6 | 관제 대시보드 / 실시간 모니터링 / 시뮬레이션 뷰어 |
| **2) Backend** | Java 21, Spring Boot 3.3.4, MyBatis 3.0.3, REST API, WebSocket(STOMP), Spring Integration MQTT + Eclipse Paho 1.2.5 | 업무 로직 / API / 이벤트 처리 / 실시간 상태 중계 |
| **3) Database** | MySQL 8.0 | 작업 이력 / 상태 데이터 / 사용자 정보 |
| **4) Messaging** | Eclipse Mosquitto 2, MQTT over TLS `:8883`, `allow_anonymous false` | 설비·로봇 상태 수집 / 이벤트 브로커 |
| **Streaming Relay** | MediaMTX, RTSP 입력 `:8554` → WebRTC 재생 `:8889`, ICE `:8189` | 시뮬레이션 화면 중계 |

**포트**: `:3000` 프론트 · `:8080` 백엔드 · `:8883` 브로커 · `:8554`·`:8889`·`:8189` MediaMTX.

### 그룹 B — 측정 스테이션 (전용 PC)

| 블록 | 구성 | 역할 |
|---|---|---|
| **5) Station Measurement** | Logitech BRIO 100 (USB 1920×1080), TF-Nova 거리계 (시리얼, FoV 14°), RTMDet-m + ONNX Runtime (`box`·`pallet` 2클래스), OpenCV | 화물 치수 · 전복 위험(`tipping`) · 편하중(`load_balance`) 측정 |

### 그룹 C — 실제 무인 지게차

| 블록 | 구성 | 역할 |
|---|---|---|
| **6) Onboard Vision** | RTMDet-s, TensorRT FP16, OpenCV, `pallet`·`hole` 2클래스 | 파렛트·구멍 검출 / 포크 정렬 오차 산출 |
| **7) Autonomous Driving** | ROS 2 Humble, Nav2, AMCL, SLAM, robot_localization | 맵 생성 / 위치 추정 / 경로 계획 / 자율주행 |
| **8) Edge** | Jetson Orin Nano (JetPack 6 / L4T R36.4.7), CUDA 12.6, TensorRT 10.3, USB 카메라 1280×720, YDLIDAR X4-Pro | 온보드 AI 추론 / 센서 처리 / 로봇 제어 상위 계층 |
| **9) Embedded** | ESP32-S3, ESP-IDF / FreeRTOS, I²C로 PCA9685(PWM)·MPU6500(IMU), MG996R 조향 서보, 구동 모터, 포크 리프트 | 모터 제어 / 센서 인터페이스 / 실시간 제어 |

**6·7은 8(Jetson) 위에서 돈다.** 나란히 그리되 8에 얹힌 관계가 드러나야 한다.

### 그룹 D — 디지털 트윈 / 시뮬레이션

| 블록 | 구성 | 역할 |
|---|---|---|
| **10) Digital Twin** | NVIDIA Isaac Sim 5.1, Omniverse, USD | 가상 창고 다중 지게차 시뮬레이션 / 실물 위치 반영 |

> ⚠️ 실행 호스트는 미정이다(2026-08-03에 GPU 서버 런타임을 전부 내렸다). **실물 지게차의 Nav2는 Jetson에서 돈다** — 이 둘을 혼동해 트윈을 지게차 그룹에 넣지 말 것.

### 그룹 밖 — 하단 띠

| 블록 | 구성 |
|---|---|
| **11) Infrastructure** | Docker Compose, AWS EC2, GitLab CI/CD, systemd |
| **Development Tools** | Maven, npm, Colcon, CMake, pytest, H2(테스트 인메모리 DB), COCO(라벨 포맷) |
| **학습 전용 스택** | PyTorch, MMDetection, MMDeploy, Python 3.10 — **GPU 서버 전용이며 런타임이 아니다** |

---

## 2. 그룹 테두리 색

| 그룹 | 포함 블록 | 색 |
|---|---|---|
| A 클라우드 / 플랫폼 (AWS EC2) | 1, 2, 3, 4, Streaming Relay | 남색 `#1B3B6F` |
| B 측정 스테이션 (PC) | 5 | 파랑 `#0B5FA5` |
| C 실제 무인 지게차 | 6, 7, 8, 9 | 초록 `#2E7D32` |
| D 디지털 트윈 / 시뮬레이션 | 10 | 청록 `#12796B` |

11번과 Development Tools는 그룹 밖 하단 띠에 둔다.

---

## 3. 연결

실선은 데이터 흐름, 점선은 스트리밍·동기화. 라벨은 아래 문자열을 **그대로** 쓴다.

| # | 구간 | 방식 | 라벨 | 검증 상태 |
|---|---|---|---|---|
| 1 | Frontend ↔ Backend | REST | `REST API` | 완료 |
| 2 | Frontend ↔ Backend | WebSocket | `WebSocket / STOMP` | 완료 |
| 3 | Backend → Database | JDBC | `SQL` | 완료 |
| 4 | Backend ↔ Messaging | MQTT (Eclipse Paho) | `MQTT (Paho)` | 완료 |
| 5 | Messaging → 측정 스테이션 | MQTT TLS | `fast/station/measure_request` | 왕복 검증 완료 |
| 6 | 측정 스테이션 → Backend | REST | `POST /api/stations/measurements` | 왕복 검증 완료 |
| 7 | Messaging ↔ Edge(Jetson) | MQTT TLS `:8883` | `forklift/{vehicleId}/command` · `.../command-result` | 부분 |
| 8 | Edge(Jetson) ↔ Embedded(ESP32) | UART 115200 8N1 | `CRC-16 · 500ms 워치독` | 완료 |
| 9 | Digital Twin → Streaming Relay | RTSP `:8554` | `RTSP (ffmpeg)` | 송출 확인 |
| 10 | Streaming Relay → Frontend | WebRTC `:8889` | `WebRTC 재생` | 시연 망 UDP 차단 |
| 11 | Digital Twin → Frontend | Omniverse WebRTC `:49100`·`:47998` | `Omniverse WebRTC (직결)` | 9·10으로 대체 |
| 12 | Digital Twin ↔ Messaging | MQTT | `상태 동기화` | 미검증 |

**9·10과 11은 서로 다른 파이프라인이다.** 하나로 뭉뚱그리면 틀린 그림이 된다. 11은 Omniverse 자체 WebRTC SDK 직결이고, 9·10은 워크스테이션 ffmpeg가 화면을 캡처해 MediaMTX로 중계하는 경로다.

### 3-1. 그리면 안 되는 연결

**Database ↔ Messaging 직결.** MySQL과 Mosquitto는 서로 모른다. MQTT로 들어온 메시지는 전부 백엔드(Spring Integration MQTT)를 거쳐 MyBatis로 DB에 반영된다. 이 화살표가 있으면 틀린 그림이다.

### 3-2. 검증 상태 표기

범례에 검증 상태를 함께 싣는다. **완료는 초록, 미완은 주황**으로 구분한다. 심사에서 "어디까지 됐냐"는 질문이 반드시 나오므로 그림이 스스로 답하게 만든다.

미완으로 칠할 것 — 7번(백엔드 → Nav2 MOVE는 배선까지만 검증, 실주행 미검증 / Jetson ↔ 브로커는 지금 없어진 평문 브로커 기준 검증이라 TLS 재검증 필요), 10번, 12번. 여기에 **Nav2 ↔ 포크 정렬의 `/cmd_vel` 인계 규칙 없음**을 지게차 그룹 안에 표시한다.

---

## 4. 이 시스템에 **없는** 것

그림에 들어가면 사실과 다르므로 넣지 않는다.

- **CVAT** — 라벨링은 레포 자체 도구(`ai/src/dataset/label_onboard.py`)로 했다. 경로·파일 이름에 `cvat`가 남아 있지만 이름뿐이다.
- **YOLO / Ultralytics** — 검토했으나 채택하지 않았다.
- **OV5647 CSI 카메라** — 커넥터·드라이버 문제로 USB 카메라로 교체했다.
- **강화학습 기반 포크 정렬** — 기하로 정확히 계산되는 관계라 채택하지 않았다.
- **GPU 서버의 런타임 서비스** — Mosquitto·Isaac Sim·Nav2 모두 2026-08-03에 내려갔다. GPU 서버는 학습 전용이다.
- **지게차 위의 PyTorch / MMDetection / ONNX Runtime** — 학습 스택과 스테이션 스택이다. 지게차에서 도는 것은 TensorRT뿐이다.
- **지게차 위의 Logitech BRIO / TF-Nova** — 측정 스테이션 장비다. 지게차 카메라는 1280×720 USB 카메라다.

---

## 5. 정확한 문자열 (오탈자 방지)

지금까지 반복해서 깨진 항목들이다. 아래 표기를 그대로 쓴다.

| 올바른 표기 | 자주 나오는 오기 |
|---|---|
| `STOMP` | STDMP |
| `@stomp/stompjs` · `sockjs-client` | @atamp/storupjs, sovina-chvnt |
| `Tailwind CSS 4` | Teilwind |
| `NVIDIA Omniverse` | Omviverse |
| `@nvidia/ov-web-rtc` | ov-web-ric |
| `Eclipse Paho 1.2.5` | Paho 1.2.8 |
| `WebSocket` | WebSocker |
| `MediaMTX` | MediaMTx, Media MTX |
| `systemd` | syttemd |
| `AMCL` | AWCL |
| `Nav2` | Nov2, Nav 2 |
| `robot_localization` | Rvbot localization |
| `ESP32-S3` | ESP32-53, ESP32-33 |
| `PCA9685` | PCA8685 |
| `MPU6500` | MPU5800 |
| `MG996R` | MG006R |
| `YDLIDAR X4-Pro` | YOUDAR, YDLIDAR X4 |
| `CUDA 12.6` | CUDA 12.5 |
| `L4T R36.4.7` | R36.3.0 |
| `i15a304.p.ssafy.io` | i15a904.p.seafylu |
| `fast/station/measure_request` | huk/station/measure_request |
| `POST /api/stations/measurements` | POST/stations/measurements |
| `:8080` `:3000` `:8883` | :6080, :9883 |
| `2클래스 pallet · hole` | 2플레스, Classes: pallet |

---

## 6. 그리기 규칙

- **번호**: 1~11을 빠짐없이, 중복 없이. 지금까지 만든 판마다 번호가 빠지거나(9번, 5번) 겹쳤다(7번 두 개, 8번 두 개, 11번 두 개).
- **언어**: 설명 문구는 한국어로 통일한다. 블록 제목만 영문 고유명사를 쓴다(`1) Frontend`, `8) Edge`). 한 그림 안에서 어떤 블록은 영어 설명, 어떤 블록은 한국어 설명이 되지 않도록 한다.
- **화살표**: §3 표 그대로. 라벨은 §3의 "라벨" 열 문자열을 그대로 쓴다.
- **범례**: 그룹 색 + 검증 상태(완료 초록 / 미완 주황) + "그리면 안 되는 연결"을 함께 싣는다.

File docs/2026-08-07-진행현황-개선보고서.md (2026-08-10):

# 진행 현황 · 개선 방향 보고서

작성 2026-08-07 · 데모 2026-08-10 (**3일 남음**)
점검 대상: 브랜치 `feature/S15P11A304-52-fr-304-2-회피-경로-통합-현장-튜닝`

이 문서는 특정 시점의 **스냅샷**이다. 갱신하지 않고 다음 점검 때 새로 쓴다.
상시 기준은 `센서-측정-칼리브레이션.md`, `isaac-sim-연동-인수인계.md` 쪽이다.

---

## 1. 한눈에 보기

| 영역 | 상태 | 근거 |
|---|---|---|
| 센서 칼리브레이션 (A~J) | ✅ 완료·머지 | `센서-측정-칼리브레이션.md` §3.5 |
| 엔코더 (펌웨어~ROS) | ✅ 완료·머지 | `/wheel/twist` 50 Hz 발행 확인 |
| 장애물 회피 현장 튜닝 | ⚠️ 진행 중·미커밋 | 아래 §3 |
| 현장 SLAM 자동 한 바퀴 | ⚠️ 신규·미커밋 | 1057줄, 미검증 |
| Nav2 ↔ 오도메트리 연결 | ✅ 수정됨 | `odom_topic` → `/odometry/filtered` |
| 실물 → MQTT 텔레메트리 | ❌ 꺼져 있음 | `mqtt_enabled: false` |
| 시뮬 연동 규격 합의 | ❌ 미해결 | 충돌 3건 (`isaac-sim-연동-인수인계.md` §2) |
| 형상 관리 | ⚠️ 위험 | 수정 18 + 미추적 19, 커밋 없음 |

---

## 2. 완료된 것

### 2.1 센서 칼리브레이션

A~J 전 단계 통과. `2ee4e14`(브랜치 `-109`)와 `6639594`(브랜치 `-178`)로 develop
머지 완료. **값은 설정 파일이 소유하므로** 여기 옮겨 적지 않는다 —
`docs/센서-측정-칼리브레이션.md` §3.5 에 결과와 근거가 있다.

측정 중 드러난 사실 넷이 특히 중요하다.

| 발견 | 왜 중요한가 |
|---|---|
| 라이다가 90° 돌아 장착 | rf2o 가 전진을 옆걸음으로 계산하고 있었다 |
| 자이로 잡음은 라이다 켜고 재야 함 | 꺼놓고 재면 15배 작게 나온다 |
| 두 ToF 피치가 4° 다름 | 피치를 모르면 1 m 앞 가짜 장애물이 생긴다 |
| 직물 바닥이 단발 반사를 뿌림 | 마스킹으로 못 잡아 지속성 필터로 해결 |

### 2.2 엔코더

JGA25-370 (13 PPR × 1:9.6 = 499.2 counts/rev, 0.3776 mm/count). PCNT 하드웨어
4체배라 엣지마다 인터럽트가 없다. `@ENC` 프레임 → `/wheel/twist` 50 Hz.

**아직 EKF 에 융합하지 않았다** (§4).

### 2.3 측정 도구 9종

`firmware/esp32/motor_controller/tools/` 에 있다. 재측정이 필요할 때 절차서
없이도 돌릴 수 있다.

`tof_probe` `tof_identify` `tof_geometry_check` `tof_wall_check` `tof_mask_learn`
`gyro_scale_check` `yaw_noise_check` `encoder_scale_check` `emi_check`
그리고 `flash.sh` (파이썬 불일치·포트 점유를 대신 처리).

---

## 3. 진행 중인 것 — 브랜치 `-52`, 전부 미커밋

`git diff` 로 확인한 실제 변경이다.

| 갈래 | 파일 | 무엇이 바뀌었나 |
|---|---|---|
| Nav2 운동 모델 | `nav2_params.yaml` | `allow_reversing` false, `REEDS_SHEPP`→`DUBIN`, goal tol 0.25→0.10 |
| 회피 튜닝 | `obstacle_avoidance.yaml` | 정지거리 0.45→**0.25**, 속도배율 0.25→0.80, 요레이트 0.18→0.02, 후방 정지·출발 킥 신규 |
| 구동 포락선 | `teleop.yaml` | drive percent 35/60 → 18/45 |
| 펌웨어 | `task_tof.c` | INT 복구 (아래) |
| 신규 | `field_lap_*`, `field_slam_nav2.launch.py` 외 | 현장 SLAM 자동 한 바퀴, 1057줄 |
| 트윈 | `orin_telemetry.yaml` + 런치 등록 | 인수인계 지적 #2 반영 |

### 잘 잡은 것 — ToF INT 복구

```
읽기 실패 → active-low INT 가 걸린 채로 남음 → 다음 하강 엣지가 없음
        → 재부팅까지 그 센서가 침묵
```

3프레임(200 ms) 놓치면 폴링으로 읽어 INT 를 풀어준다. **증상이 "가끔 한쪽이 안
보인다"로만 나타나는 종류**라 찾기 어려운 버그였다. 실제로 이 세션 중
`/tof/left/points` 가 조용히 멈춘 일이 있었는데 그때는 원인을 못 찾고 재기동으로
넘어갔다 — 이 수정이 그 현상을 설명한다.

### 인수인계 지적 2건 반영 확인

| 지적 | 상태 |
|---|---|
| `nav2_params.yaml` 의 `odom_topic` 이 발행자 없는 `/odom` | ✅ `/odometry/filtered` 로 수정 (48·401행) |
| `orin_telemetry` 노드를 아무도 안 띄움 | ✅ `field_slam_nav2.launch.py:104` 에 등록 |

---

## 4. 남은 과제

| # | 과제 | 상태 | 소유 |
|---|---|---|---|
| 1 | MQTT 토픽 계열 확정 | ❌ **오히려 고착됨** — `orin_telemetry.yaml` 이 `fast/v1` 로 설정돼 백엔드의 `forklift/` 와 갈림 | E, F |
| 2 | 텔레메트리 실제 발행 | ❌ `mqtt_enabled: false`, `origin_configured: false` | D |
| 3 | yaw 단위 합의 (degree vs radian) | ❌ | E, F |
| 4 | `base_link` 기준점 합의 | ❌ 축거 0.144 m 어긋남 | C, D, F |
| 5 | 구동 모터 EMI (I단계) | ⚠️ 스텝퍼만 검증 (150초 증가 0) | D |
| 6 | 엔코더 → EKF `twist0` | ⚠️ 발행 중이나 미융합 | D |
| 7 | 현장 SLAM 한 바퀴 실주행 | ⚠️ 코드만 있고 미검증 | D |
| 8 | 시뮬 RTX 라이다 ActionGraph | ❌ 레포에 없음 | F |

---

## 5. 개선 방향 — 발견한 위험 7건

### 5.1 CRLF 때문에 리뷰가 불가능한 파일이 있다

`ai/src/control/fork_servo.py` 의 diff 는 **2574줄**이다. 그런데:

```bash
git diff --stat --ignore-all-space ai/src/control/fork_servo.py
#  1 file changed, 104 insertions(+), 8 deletions(-)
```

**실제 변경은 104줄인데 파일 전체가 재작성된 것처럼 보인다.** 줄바꿈이 CRLF 로
바뀐 탓이다. 이 상태로는 리뷰어가 실질 변경을 찾을 수 없고, 충돌이 나면 병합도
어렵다.

추적 파일 중 CRLF 는 4개다.

```
ai/scripts/onboard_fork_align_node.py
ai/src/control/fork_servo.py
ros2_ws/README.md
ros2_ws/src/forklift_teleop/behavior_trees/navigate_to_pose_no_spin.xml
```

**권장**: 저장소 루트에 `.gitattributes` 를 두어 고정한다.

```
* text=auto eol=lf
```

그 뒤 위 4개 파일을 LF 로 정규화해 **줄바꿈만 담은 커밋 하나**로 분리한다.
기능 변경과 섞으면 같은 문제가 반복된다.

### 5.2 안전 파라미터가 규격 문서와 갈라졌다 — 가장 중요

| 출처 | 정지거리 |
|---|---|
| `docs/ros2/obstacle-avoidance-validation.md:23,32` | **0.45 m** (두 곳에 명시) |
| `config/obstacle_avoidance.yaml` (현재) | **0.25 m** |

설정 주석에 "사용자 현장 충돌 방지 조치와 명시적 승인 하에" 라고 근거가 남아
있는 것은 좋다. 문제는 **검증 문서가 따라오지 않았다**는 점이다.

지금 상태로 4개 시나리오를 돌리면 합격 기준이 없다. 0.45 m 로 판정하면 전부
불합격이고, 0.25 m 로 판정하면 근거 문서가 없다.

**권장**: 검증 문서의 0.45 를 0.25 로 고치고, **왜 줄였는지와 남은 여유
(footprint 전면 0.190 m 대비 0.06 m)** 를 함께 적는다. 데모 전에 회피 시나리오를
다시 돌릴 계획이라면 이게 선행 조건이다.

### 5.3 벤더 패키지 2개가 버전 관리 밖에 있다

```
ros2_ws/src/rf2o_laser_odometry/     미추적
ros2_ws/src/ydlidar_ros2_driver/     미추적
```

`.gitignore` 에도 없다. **새로 클론하면 빌드가 안 된다.** 둘 다 주행에 필수인데
"어디서 받아서 어떻게 넣는지"가 어디에도 없다.

**권장**: 둘 중 하나를 고른다.

- 그대로 커밋한다 (재현성 확보, 저장소가 커짐)
- `.gitignore` 에 넣고 **설치 절차를 `ros2_ws/README.md` 에 적는다** (출처 URL·커밋 해시 포함)

어느 쪽이든 지금처럼 방치하는 것보다 낫다.

### 5.4 실행 절차가 지목하는 스크립트가 미추적이다

`ros2_ws/FIELD_SLAM_MQTT.md` 는 `tools/field_lap_session.sh` 를 실행 절차로
지목하는데, `ros2_ws/tools/` 전체가 미추적이다.

같은 디렉터리의 `left_recovery.py` · `rear_recovery.py` 는 문서가
**"임시 복구 스크립트부터 실행하지 말라"**고 경고하는 대상으로 보인다. 그렇다면
더더욱 버전 관리에 들어가서 무엇이 임시인지 표시돼야 한다.

### 5.5 정체불명 0바이트 파일 2개

```
./4?@W@8                                    0 bytes, Aug 5 12:57
./firmware/esp32/motor_controller/4?@W@8    0 bytes, Aug 5 12:57
```

잘못 입력된 명령의 부산물이다. 삭제한다.

### 5.6 커밋되지 않은 변경이 너무 크다

데모 3일 전에 **수정 18개 + 미추적 19개**, 커밋 0개. 되돌릴 지점이 없고 유실
위험이 크다. 지금 디스크가 날아가면 현장 튜닝 결과가 통째로 사라진다.

**권장**: 갈래별로 나눠 커밋한다. 뒤섞어 한 번에 커밋하면 문제가 생겼을 때 어느
변경이 원인인지 못 가린다.

1. 줄바꿈 정규화 (`.gitattributes` + 4개 파일)
2. 펌웨어 ToF INT 복구
3. 회피·구동 파라미터 현장 튜닝 (+ 검증 문서 갱신)
4. Nav2 운동 모델 (DUBIN·후진 금지)
5. 현장 SLAM 자동 한 바퀴 (신규 기능)
6. 트윈 텔레메트리 배선

### 5.7 텔레메트리가 조용히 꺼져 있다

`orin_telemetry.yaml` 의 `mqtt_enabled: false`, `origin_configured: false`.
노드는 정상 기동하고 로그도 정상으로 보이는데 **밖으로 아무것도 안 나간다.**

이 프로젝트는 같은 함정을 이미 겪었다 — MOVE 명령이 전부 거절되는데 그 사실이
아무 데도 안 찍혀 엉뚱한 곳을 팠다(S15P11A304-192). 그 교훈으로
`mqtt_bridge_node._build_command_adapter()` 는 **어느 쪽으로 떨어졌는지 반드시
로그에 남긴다.**

**권장**: 같은 패턴을 텔레메트리에도 적용한다. `mqtt_enabled: false` 이거나
`origin_configured: false` 면 기동 시 경고를 남긴다. "조용히 무력한 상태로 도는
일은 없어야 한다"는 원칙이 이미 코드에 있으니 그것을 따르면 된다.

---

## 6. 권장 순서 — 3일 기준

**유실·안전 위험이 먼저다. 기능 추가는 그 다음이다.**

| 순위 | 항목 | 근거 | 소요 |
|---|---|---|---|
| 1 | 갈래별 커밋 (§5.6) | 유실 위험. 지금 날아가면 복구 불가 | 30분 |
| 2 | 검증 문서 정지거리 정정 (§5.2) | 안전 기준이 없는 상태 | 15분 |
| 3 | `.gitattributes` + 줄바꿈 정규화 (§5.1) | 리뷰·병합 불가 해소 | 15분 |
| 4 | 벤더 패키지 처리 (§5.3) | 재현성 | 30분 |
| 5 | 현장 SLAM 한 바퀴 실주행 | 신규 1057줄이 미검증 | 반나절 |
| 6 | 구동 모터 EMI (I단계 잔여) | 주행 중 센서 신뢰성 | 10분 |
| 7 | 텔레메트리 발행 켜기 + 경고 추가 (§5.7, §4-2) | 트윈 연동 선행 조건 | 1시간 |
| 8 | 시뮬 규격 3건 합의 (§4-1,3,4) | 합의라 시간 예측 불가 — **오늘 착수** | — |

**8번을 오늘 시작할 것을 권한다.** 코드가 아니라 사람 사이의 합의라 리드타임이
길고, 정해지지 않으면 연동 코드를 써도 버려야 한다.

**5·6번은 데모 시연 내용에 직결된다.** 자동 한 바퀴를 시연할 계획이면 5번이
필수이고, 그 주행 중 센서가 흔들리면 6번이 원인일 수 있다.

---

## 7. 관련 문서

| 문서 | 언제 |
|---|---|
| `docs/센서-측정-칼리브레이션.md` | 센서 값의 근거·재측정 절차 |
| `docs/isaac-sim-연동-인수인계.md` | 시뮬 연동 규격 충돌·함정 |
| `ros2_ws/FIELD_SLAM_MQTT.md` | 현장 SLAM 실행 절차 |
| `docs/nav2-장애물대응-원인분석.md` | 장애물 앞 정지·유령 표시의 원인과 조치 |
| `docs/ros2/obstacle-avoidance-validation.md` | 회피 검증 시나리오 (정지거리 0.25 m 로 정정 완료) |

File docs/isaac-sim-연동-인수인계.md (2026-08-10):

# Isaac Sim 연동 인수인계

실물 지게차(1/10 미니어처) 쪽 센서 칼리브레이션이 2026-08-06 에 전 단계를 통과했다.
이 문서는 **그 결과를 Isaac Sim 트윈과 붙이려는 사람이 알아야 할 것**을 모은 것이다.

읽는 순서: §1 로 어느 규격이 살아 있는지 파악하고, §2 의 충돌 3건을 먼저 합의한다.
**§2 가 정해지기 전에는 연동 코드를 써도 버려야 한다.**

---

## 0. 지금 상태 요약

| | 상태 |
|---|---|
| 실물 센서 칼리브레이션 | ✅ A~J 전 단계 통과 (`센서-측정-칼리브레이션.md` §3.5) |
| 실물 Nav2 로컬 costmap | ✅ ToF 가 라이다 사각의 낮은 상자를 마킹, 회전해도 유지 |
| 실물 → MQTT 텔레메트리 | ❌ **두 경로 모두 죽어 있음** (§6-1) |
| 시뮬 Nav2 단독 주행 | ✅ 팀원 PC 에서 동작 (`isaac_sim/nav2/RUN.md`) |
| 시뮬 ↔ 실물 좌표 왕복 | ❌ 미검증 |
| 규격 합의 | ❌ 충돌 3건 미해결 (§2) |

---

## 1. 규격 문서 지도 — 어느 것이 살아 있나

프로젝트에 규격 문서가 네 벌 있고 **서로 다른 것을 말한다.** 코드가 실제로 무엇을
하는지 확인해 판정했다.

| 문서 | 상태 | 판정 근거 |
|---|---|---|
| `docs/backend-message/communication-protocol.md` | **살아 있음** | `mqtt_bridge_node.py` 가 여기 적힌 `forklift/{id}/...` 토픽을 그대로 씀 |
| `ros2_ws/orin-pose-spec.md` | **좌표 계약만 유효** | `orin_telemetry_model.py` 의 `SCALE = 10.0` 이 이 문서를 따름. 단 토픽은 다름 |
| `isaac_sim/docs/interface-spec.md` | **초안 v0.1** | 문서 §9 에 미합의 9건이 ⚠️ 로 남아 있음. 좋은 설계 근거지만 계약으로 쓰면 안 됨 |
| `isaac_sim/nav2/README.md`, `RUN.md` | **시뮬 실행 절차로 유효** | 단 경로가 전부 `/home/ubuntu/forklift_ws` — 이 Orin 에선 그대로 못 씀 |

**요지**: 백엔드와 붙는 계약은 `communication-protocol.md`, 좌표 축척 규칙은
`orin-pose-spec.md`, 시뮬 기동 절차는 `isaac_sim/nav2/RUN.md`. `interface-spec.md`
는 설계 의도를 이해할 때만 읽는다.

---

## 2. 결정된 사항 (2026-08-07)

세 항목 모두 정리됐다. 아래는 결론과 근거이고, 값 자체는 각 설정 파일이
소유한다.

### 2.1 MQTT 토픽 — 충돌이 아니라 **채널이 둘**이다

처음에 "두 계열 중 하나로 통일해야 한다" 고 적었는데, 그건 상황을 잘못 읽은
것이었다. 실차는 **두 계열을 동시에 발행하고 있고 용도가 다르다**:

| 계열 | 발행 주체 | 쓰는 쪽 |
|---|---|---|
| `forklift/{id}/status` · `location` · `path` · `command-result` | `bridge_core.py` | 백엔드 (관제 화면·DB·WebSocket) |
| `fast/v1/vehicle/{id}/telemetry` | `orin_telemetry.py` | 트윈 / 아이작 심 |

**아이작 심 쪽은 `fast/v1/...` 을 쓰면 된다.** 스펙은
`isaac_sim/docs/interface-spec.md` 가 소유한다. 백엔드 계열을 건드릴 필요가
없다 -- 그쪽은 이미 코드 200곳 이상이 붙어 있다.

### 2.2 각도 단위 — 아이작 심 채널은 **라디안**

이것도 2.1 과 같다. 채널마다 단위가 다르고, **변환은 이미 되어 있다**:

| 채널 | 필드 | 단위 | 변환 지점 |
|---|---|---|---|
| `fast/v1/...` (트윈·심) | `pose.yaw` | **라디안** −π ~ +π | `orin_telemetry.py` `normalize_angle` |
| `forklift/...` (백엔드) | `heading` | 도 [0, 360) | `dto.py` `quaternion_to_heading` |

`quaternion_to_heading` 이 `math.degrees()` 후 `normalize_heading()` 을 태운다.
처음에 "한쪽이 틀렸다" 고 적었지만 실제로는 각 채널이 자기 단위로 나가고 있다.

**아이작 심 쪽은 라디안을 그대로 쓰면 된다.** 백엔드의 도(degree) 표기는 이미
Java 코드 200곳 이상이 붙어 있어 건드릴 이유가 없다.

⚠️ 필드명도 다르다(`heading` vs `pose.yaw`). 같은 값이 아니라 **다른 채널의 다른
필드**라고 읽어야 한다 -- 한쪽 이름으로 다른 쪽을 찾으면 없다.

⚠️ 축척은 각도에 적용하지 않는다. 위치만 ×10 이고 yaw 는 그대로다.

### 2.3 `base_link` 기준점 — **전륜 구동축** 중심

| 출처 | 정의 | |
|---|---|---|
| `ros2_ws/README.md:76` | 전륜 구동축 중심 | 맞음 |
| `docs/센서-측정-칼리브레이션.md:39` | 전륜 구동축 중심 (REP-103) | 맞음 |
| `ros2_ws/orin-pose-spec.md:80` | 뒷바퀴 축 중심 | **오기 — 수정 필요** |

실물 코드와 모든 static TF 가 전륜 구동축 기준이고, 2026-08-07 에 실차에서
재확인했다. 후륜(조향)축은 `x = -0.144`(축거), footprint 뒤끝은 `-0.245` 이므로
조향축 뒤로 0.101 m 가 더 나온다.

이 기준이 어긋나면 **축거 0.144 m 만큼 밀리고, 회전할 때마다 어긋남의 방향이
바뀌어** "가끔 밀린다" 로 보인다. 트윈을 만들 때 가장 먼저 확인할 것.

⚠️ 이 기준점은 회전 기하 전체의 뿌리다. `tools/geometry_limits.py` 가 여기서
꼬리 휨(0.182 m)과 최소 회전반경(0.198 m)을 유도한다.

---

## 3. 실물 쪽 확정 사실

**값은 설정 파일이 소유한다.** 여기서는 어디를 봐야 하는지와 왜 그런지만 적는다.
숫자를 옮겨 적으면 두 번째 진실 원천이 생겨 곧 어긋난다.

### 제원을 통째로 받으려면

시뮬 차량 모델에 넣을 값 일체는 **현재 설정에서 뽑아 쓴다**:

```bash
cd ros2_ws
python3 tools/geometry_limits.py --handover
```

좌표 규약, 치수, 조향 기하(최소 회전반경·꼬리 휨), 속도 범위, 안전거리,
축척, 그리고 각 값이 사는 파일까지 한 번에 나온다.

⚠️ **출력을 문서에 붙여 넣고 끝내지 말 것.** 설정이 바뀌면 다시 돌려서
갈아끼운다. 옮겨 적은 숫자가 낡아서 생긴 사고가 이미 있었다 --
`max_linear_mps` 가 바뀌자 포크 진입이 **조용히** 파렛트를 과하게 밀기
시작했고, 로그에는 정상으로 찍혔다(§5 참고).

| 알아야 할 것 | 어디에 |
|---|---|
| 좌표 규약 (`base_link` = 전륜축, 바닥에서 30 mm 위) | `docs/센서-측정-칼리브레이션.md` §1 |
| 실측 치수·footprint·축거 | `ros2_ws/README.md` "실측 좌표계" |
| 센서 static TF (IMU·ToF 좌우) | `launch/sensor_usb.launch.py` |
| LiDAR TF | `launch/lidar_odometry.launch.py` `LIDAR_TRANSLATION`/`LIDAR_ROTATION` |
| ToF 기하·피치·필터 | `config/sensors.yaml` |
| 자이로 잡음·엔코더 스케일 | `config/sensors.yaml` |
| 운전값 (조향 범위·속도 한계) | `config/teleop.yaml` |
| 안전 봉투 (재플래시 필요) | `firmware/.../main/config.h` |

### 시뮬이 특히 알아야 할 것 넷

**1. 라이다가 90° 돌아 달려 있다.** `LIDAR_ROTATION` 의 yaw 가 `1.5708` 인 이유다.
이걸 0 으로 두면 rf2o 가 **전진할 때 옆으로 미끄러진다고 계산**한다. 시뮬에서
라이다를 배치할 때 같은 실수를 하지 않도록 알아둘 것.

**2. 후륜 조향이라 제자리 회전이 불가능하다.** Nav2 기본 트리의 `Spin` 이 영원히
끝나지 않으므로 `navigate_to_pose_no_spin.xml` 을 쓴다
(`launch/nav2_forklift.launch.py` 상단 주석). 시뮬 차량도 같은 성질이지만 원인이
다르다 — 실물은 데드밴드, 시뮬은 자전거 모델 적분. **저속 구간 거동이 서로 다르다.**

**3. 두 ToF 는 좌우 측면이 아니라 둘 다 정면이다.** 포크 갭 양쪽에서 앞을 본다.
벌리지 않은 이유는 정면 근거리 사각 때문이며 계산이
`센서-측정-칼리브레이션.md` §2.2 에 있다.

**4. 안전 봉투와 운전값은 다른 것이다.** `config.h` 의 한계는 "여기를 넘으면 기구가
상한다", `teleop.yaml` 은 "실제로 쓰는 범위". 튜닝은 항상 후자에서 한다.

---

## 4. 실물 ↔ 시뮬 차이 대조표

**모든 차이를 없앨 필요는 없다.** 무엇을 맞춰야 하고 무엇은 달라도 되는지가 핵심이다.

| 항목 | 실물 | 시뮬 | 맞춰야 하나 |
|---|---|---|---|
| 프레임 | `base_link`, `odom`, `laser_frame` | `SIM_F02_base_link` 등 | **아니오** — 둘은 MQTT 경계에서만 만난다 |
| 토픽 | `/scan`, `/cmd_vel`, `/odometry/filtered` | `/sim_f02/scan`, `/sim_f02/odom` | **아니오** |
| 축척 | 1/10 (2×3 m) | 10× (20×30 m) | **아니오 — 의도된 차이.** 변환은 Orin 발행 지점 한 곳 |
| `use_sim_time` | 하드코딩 `false` | `true` | **섞지 말 것** (아래) |
| `/scan` QoS | Best Effort | — | **예** — Reliable 로 구독하면 한 건도 못 받는다 |
| 포크 명령 | `/fork/command` String + 호밍 인터록 | `fork_cmd` Float32(m) | **예 — 호환 불가, 합의 필요** |
| `odom→base_link` | EKF 단독 | 시뮬이 직접 씀 | **이중 발행 금지** |
| Nav2 파라미터 | `ros2_ws/nav2_params.yaml` | `isaac_sim/nav2/config/nav2_sim.yaml` | **아니오** — 축척이 달라 별도 유지가 맞다 |
| costmap 관측원 | `scan tof_left tof_right` | `scan` 만 | 시뮬에 ToF 를 넣을지는 선택 (§6) |

### `use_sim_time` 함정

실물 쪽은 **16 곳에 `false` 가 하드코딩**돼 있다 (`ekf.yaml` 1곳,
`nav2_params.yaml` 15곳). 그리고 `nav2_forklift.launch.py` 의 `RewrittenYaml` 은
`default_nav_to_pose_bt_xml` 만 덮어쓰므로, **`use_sim_time:=true` 를 줘도 params
파일이 도로 `False` 로 되돌린다.**

게다가 실물 노드 대부분은 `time.monotonic()` 으로 시간을 잰다. 워치독과 신선도
판정은 `use_sim_time` 과 무관하게 벽시계로 돈다.

**시뮬용으로 Nav2 를 띄울 때는 `nav2_sim.yaml` 을 쓴다.** 실물 params 에
`use_sim_time:=true` 를 얹어 쓰려는 시도는 조용히 실패한다.

---

## 5. 함정 — 실제로 겪은 것만

### 5.1 ROS_DOMAIN_ID 를 먼저 확인한다

**실물 100 / 시뮬 0.** 같은 네트워크에서 도메인이 같으면 ROS2 는 노드를 자동으로
공유한다.

> 2026-08-04 에 실제로 겪었다 — 팀원 PC 의 Isaac Sim 노드가 젯슨에서 그대로 보였고,
> `/cmd_vel` 구독자가 2개가 됐다. **시뮬 차량이 실물 명령을 받고, 실물이 시뮬 명령을
> 받는다.** (`docs/deploy/ros-domain.md`)

```bash
echo $ROS_DOMAIN_ID
ros2 topic info /cmd_vel -v    # 내 노드 말고 다른 게 붙어 있는지
```

**연동 작업의 첫 단계는 항상 이것이다.** 이걸 건너뛰면 이후 모든 관측이 오염된다.

### 5.2 시뮬 자산에 빠진 것이 있다

- **RTX 라이다 ActionGraph 가 레포에 없다.** `RUN.md` 는 GUI 에서 손으로 만들라고만
  한다. 시뮬을 다른 PC 에서 재현할 수 없게 만드는 가장 큰 공백이다
- `ff.usd` / `ff_nophysics.usd` 도 레포에 없다 (`/home/ubuntu/forklift_ws` 에만 있음)
- `isaac_sim/nav2/` 의 경로가 전부 `/home/ubuntu/forklift_ws` 하드코딩
- `isaac_sim/config/nav2_sim.yaml` 은 **오래된 초안**이다. 현재 것은
  `isaac_sim/nav2/config/nav2_sim.yaml`. 헷갈리기 쉽다

### 5.3 파이썬 버전이 다르다

Isaac 은 python3.11, 시스템 ROS 는 3.10 이다. ROS 를 source 한 터미널에서 Isaac 을
켜면 `No module named 'rclpy._rclpy_pybind11'` 이 난다. `run_isaac_gui.sh` 가
`PYTHONPATH` 등을 지우는 이유다. **Isaac 터미널과 ROS 터미널을 분리한다.**

### 5.4 알려진 버그

`isaac_sim/scripts/twin_bridge.py` 의 `SIM_ID` 가 하이픈/언더스코어 불일치라
시뮬 메시지가 조용히 폐기된다 (`PROJECT_IMPLEMENTATION_AUDIT.md` §9-2).

---

## 6. 남은 작업

### 6.1 즉시 — 데모 전 필수

| # | 작업 | 소유 | 근거 |
|---|---|---|---|
| 1 | `nav2_params.yaml` 의 `odom_topic` 을 `/odometry/filtered` 로 (47·392행) | D | `/odom` 은 **발행자가 없다** (실행 중 확인). 컨트롤러가 속도 피드백을 못 받는다 |
| 2 | 실물 텔레메트리 경로를 살린다 | D | **두 경로 다 죽어 있다** (아래) |
| 3 | 각도 단위 합의 | E, F | §2.2 |
| 4 | `base_link` 기준점 합의 | C, D, F | §2.3 |
| 5 | MQTT 토픽 가족 확정 | E, F | §2.1 |

**#2 가 왜 급한가.** 텔레메트리가 안 나가면 트윈에 실물이 안 보인다. 두 경로 모두
막혀 있다.

- `mqtt_bridge` 는 런치되지만 `config/mqtt_bridge.yaml` 의 `location_topic`·
  `status_topic`·`path_topic` 이 **전부 빈 문자열**이라 구독을 아예 만들지 않는다
- `orin_telemetry` 는 스케일 변환(×10)까지 올바르게 구현돼 있지만 **어떤 런치
  파일도 이 노드를 띄우지 않는다.** 게다가 기본 `odom_topic` 이 `/odom` 이라
  띄워도 데이터가 없다

둘 중 하나를 골라 토픽을 `/odometry/filtered` 로 채우면 된다. §2.1 결정에 따른다.

### 6.2 연동 본작업

| # | 작업 | 소유 |
|---|---|---|
| 6 | RTX 라이다 ActionGraph 를 스크립트로 만들어 커밋 | F |
| 7 | `isaac_sim/nav2/` 경로를 상대경로나 환경변수로 | F |
| 8 | 포크 인터페이스 통일 (String+인터록 vs Float32) | C, F |
| 9 | 실물 → 브로커 → 트윈 좌표 왕복 검증 | D, E, F |
| 10 | `isaac_sim/config/nav2_sim.yaml` (구 초안) 삭제 또는 명시적 표시 | F |

### 6.3 선택 — 여유가 있으면

- **시뮬에 ToF 2개 추가.** 현재 `nav2_sim.yaml` 은 `scan` 만 본다. 실물은
  `scan tof_left tof_right` 를 `VoxelLayer` 에 넣는다. 낮은 장애물 회피를 시뮬에서
  검증하려면 필요하다
- FR-403 사전 시뮬레이션, FR-505 대수 산출

---

## 7. 연동 검증 절차

**순서대로. 각 단계를 통과한 뒤 다음으로 간다.**

### 단계 1 — 도메인 분리

```bash
# 실물(젯슨)
echo $ROS_DOMAIN_ID            # 100 이어야 한다
ros2 node list                 # 시뮬 노드가 보이면 실패

# 시뮬 PC
echo $ROS_DOMAIN_ID            # 0 또는 비어 있음
```

**합격**: 양쪽에서 서로의 노드가 보이지 않는다.

이걸 건너뛰면 이후 관측이 전부 오염된다. `/cmd_vel` 구독자가 2개가 되는 사고가
실제로 있었다.

### 단계 2 — 각자 단독 동작

| | 확인 | 합격 |
|---|---|---|
| 실물 | `ros2 topic hz /odometry/filtered` | 30 Hz 부근 |
| 실물 | `ros2 topic hz /scan` | 10 Hz 부근 |
| 시뮬 | `RUN.md` §4 의 토픽 5개 | 전부 존재 |

### 단계 3 — MQTT 왕복

브로커에 붙어 실물 텔레메트리가 올라오는지 본다.

```bash
mosquitto_sub -h <broker> -t 'forklift/+/location' -v
```

**합격**: 실물을 손으로 밀 때 좌표가 따라 움직인다.

**좌표를 반드시 검산한다.** 실물에서 잰 m 값 × 10 이 MQTT 값과 같아야 한다.
세트장 (1.55, 0.40) m → `{"x": 15.5, "y": 4.0}`.

### 단계 4 — 트윈 반영

관제 화면 또는 Isaac 에서 실물 차량이 제 위치에 보이는지.

**합격**: 실물을 세트장 한쪽 끝에서 반대쪽으로 옮기면 트윈에서도 같은 비율로 이동.

**여기서 어긋나면** §2 의 충돌 셋을 먼저 의심한다. 각도가 90° 단위로 틀리면 단위
문제(§2.2), 항상 일정하게 밀리면 기준점 문제(§2.3)다.

### 단계 5 — 명령 왕복

관제에서 목표를 주고 실물이 가는지. `command` → `command-result` 가 돌아오는지.

**`communication-protocol.md` 의 이 대목은 오래됐다.** 그 문서는 이동 adapter 가
`UnavailableCommandAdapter` 라 실제로 움직이지 않는다고 적었지만, 이후
`Nav2CommandAdapter` 가 들어와 기본으로 활성이다 (S15P11A304-192).

다만 **거절 모드로 떨어지는 경로가 둘 남아 있다.**

| 조건 | 결과 |
|---|---|
| `nav2_enabled: false` | MOVE 전부 `REJECTED` |
| `nav2_msgs` import 실패 | MOVE 전부 `REJECTED` |

둘 다 기동 로그에 시끄럽게 남는다. **`Nav2 연동 활성` 이 로그에 있는지 반드시
확인한다.** 예전에 거절 모드가 기본값이던 시절, 브리지는 정상으로 보이는데 MOVE 만
전부 실패했고 그 사실이 아무 데도 안 찍혀 엉뚱한 곳을 팠던 사고가 있었다.

---

## 8. 관련 문서

| 문서 | 언제 보나 |
|---|---|
| `docs/센서-측정-칼리브레이션.md` | 실물 센서 값의 근거와 재측정 절차 |
| `docs/backend-message/communication-protocol.md` | 백엔드와의 계약 (살아 있는 규격) |
| `ros2_ws/orin-pose-spec.md` | 좌표 축척 규칙 |
| `docs/deploy/ros-domain.md` | 도메인 분리 근거와 설정법 |
| `isaac_sim/nav2/RUN.md` | 시뮬 기동 절차 |
| `isaac_sim/docs/interface-spec.md` | 설계 의도 (계약 아님) |
| `docs/ros2/obstacle-avoidance-validation.md` | 장애물 회피 검증 시나리오 |

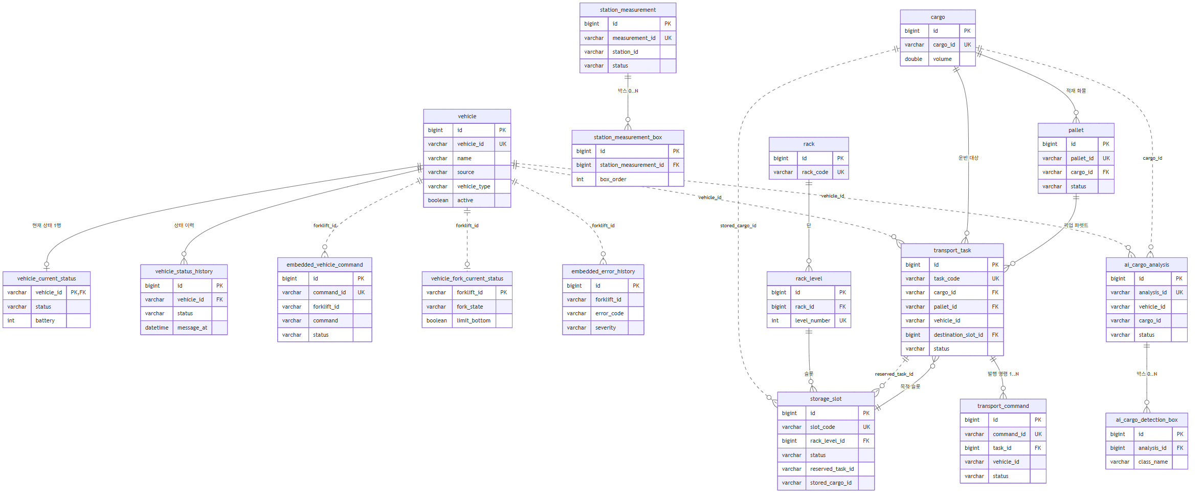
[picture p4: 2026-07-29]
docs/backend-db/erd/erd-00-overview.png

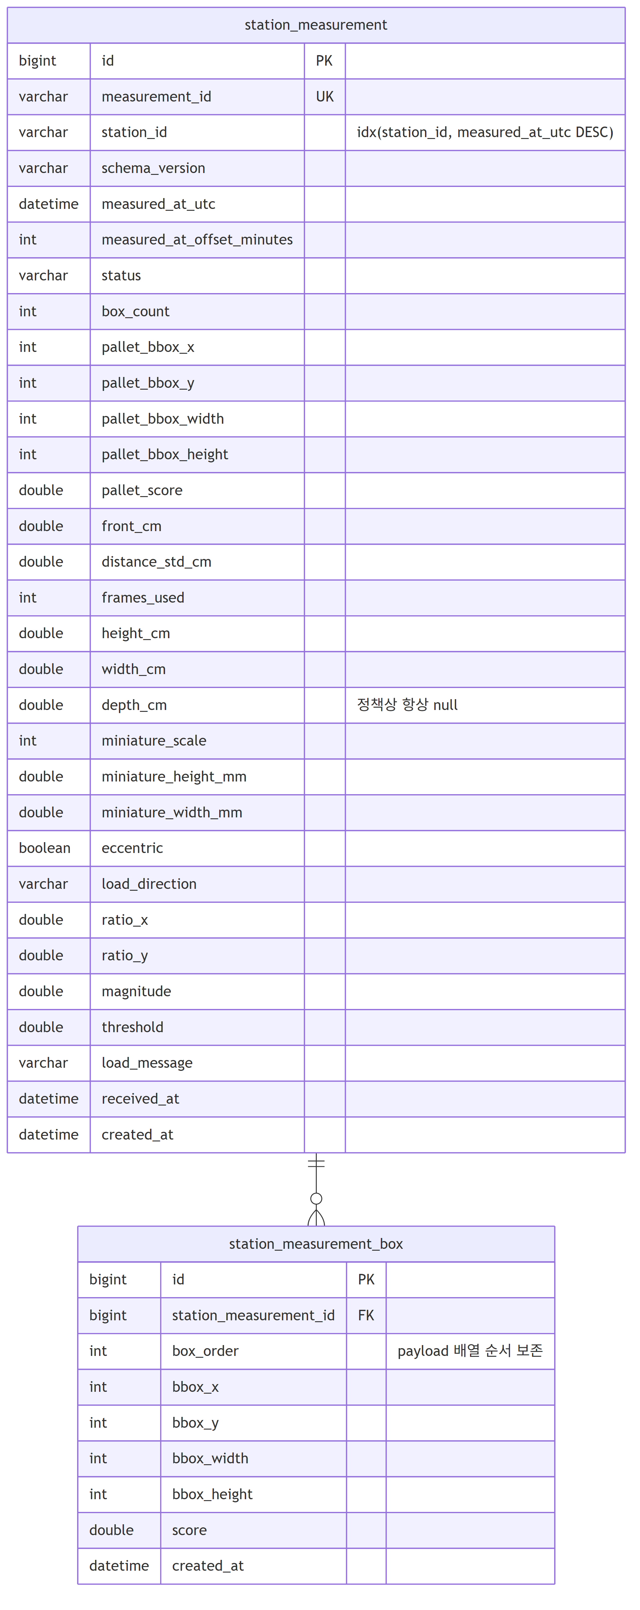
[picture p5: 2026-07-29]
docs/backend-db/erd/erd-03-station.png

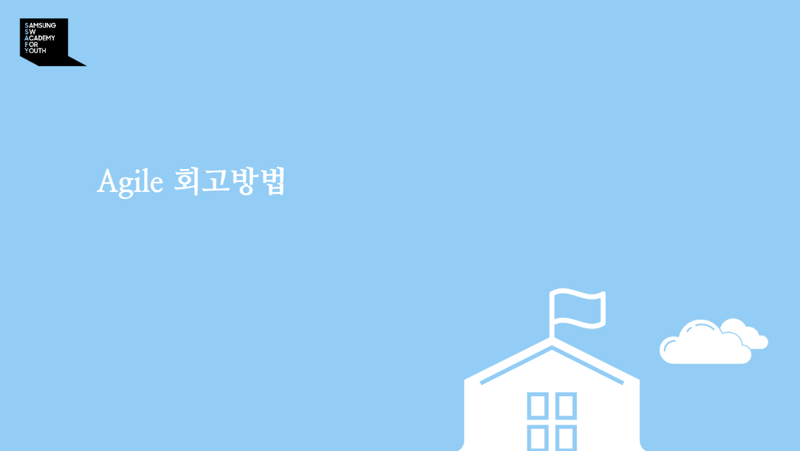
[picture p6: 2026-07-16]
docs/KPT/images/02-표지-Agile-회고방법.png

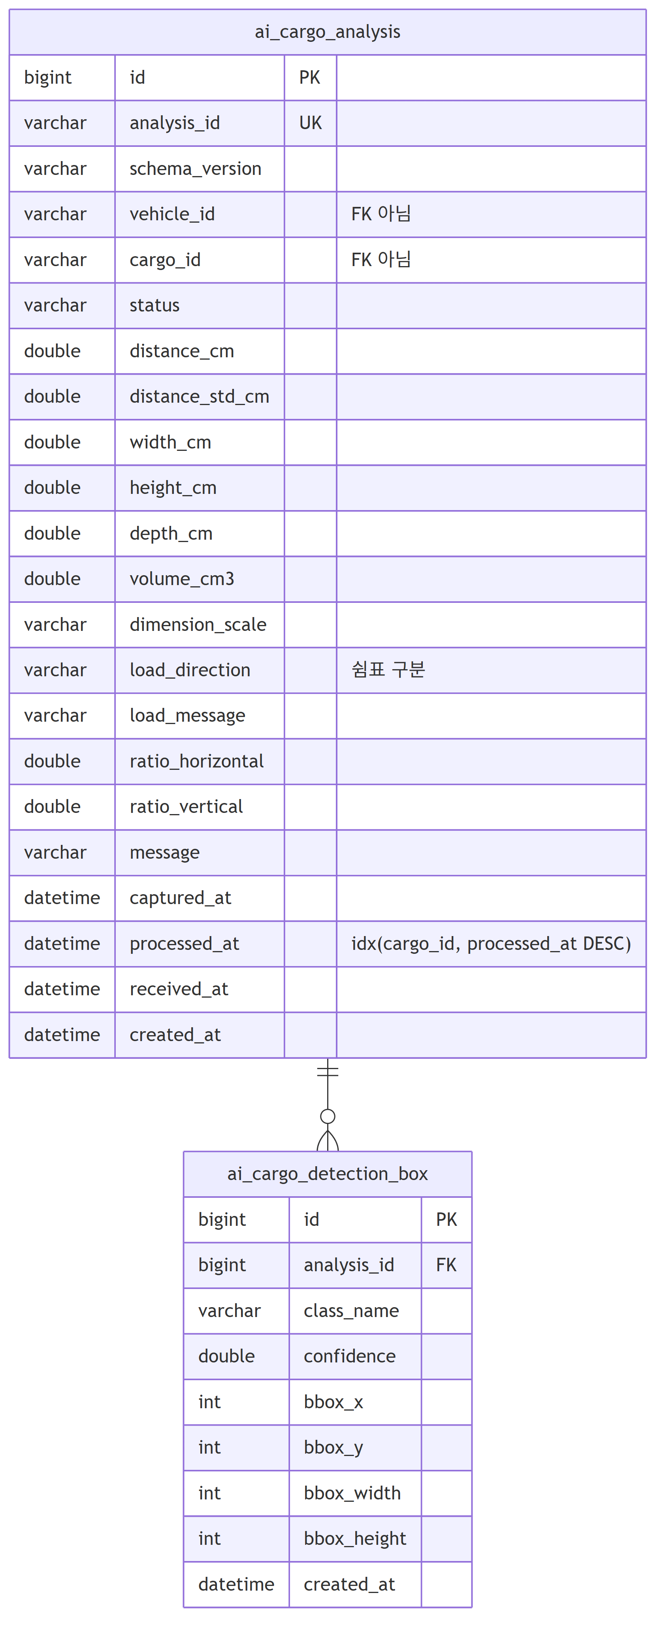
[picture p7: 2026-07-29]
docs/backend-db/erd/erd-02-ai-cargo.png

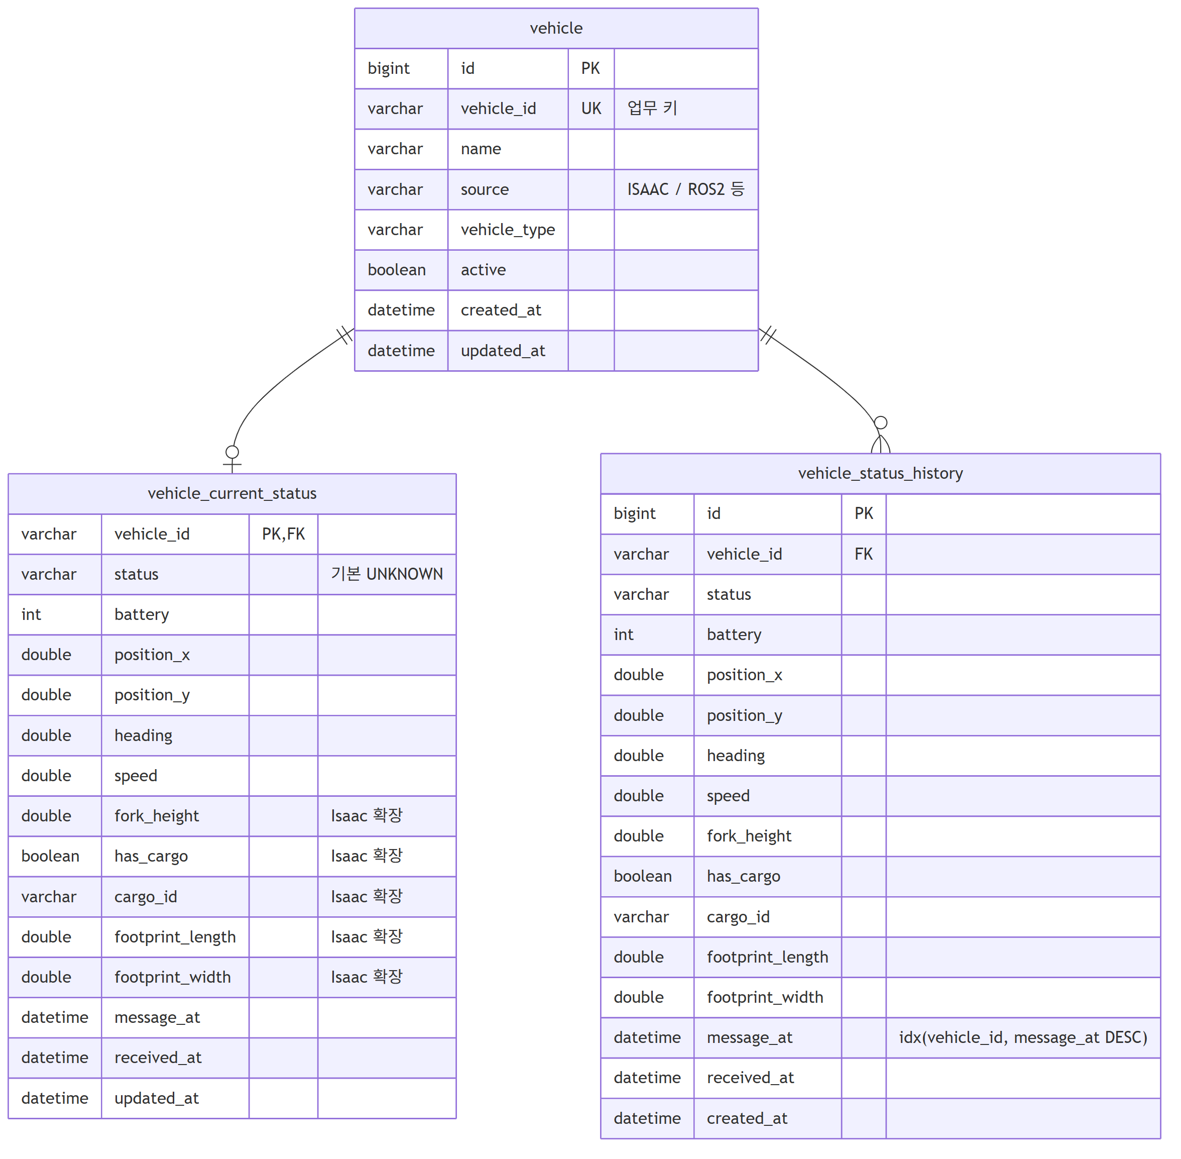
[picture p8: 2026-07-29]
docs/backend-db/erd/erd-01-vehicle.png

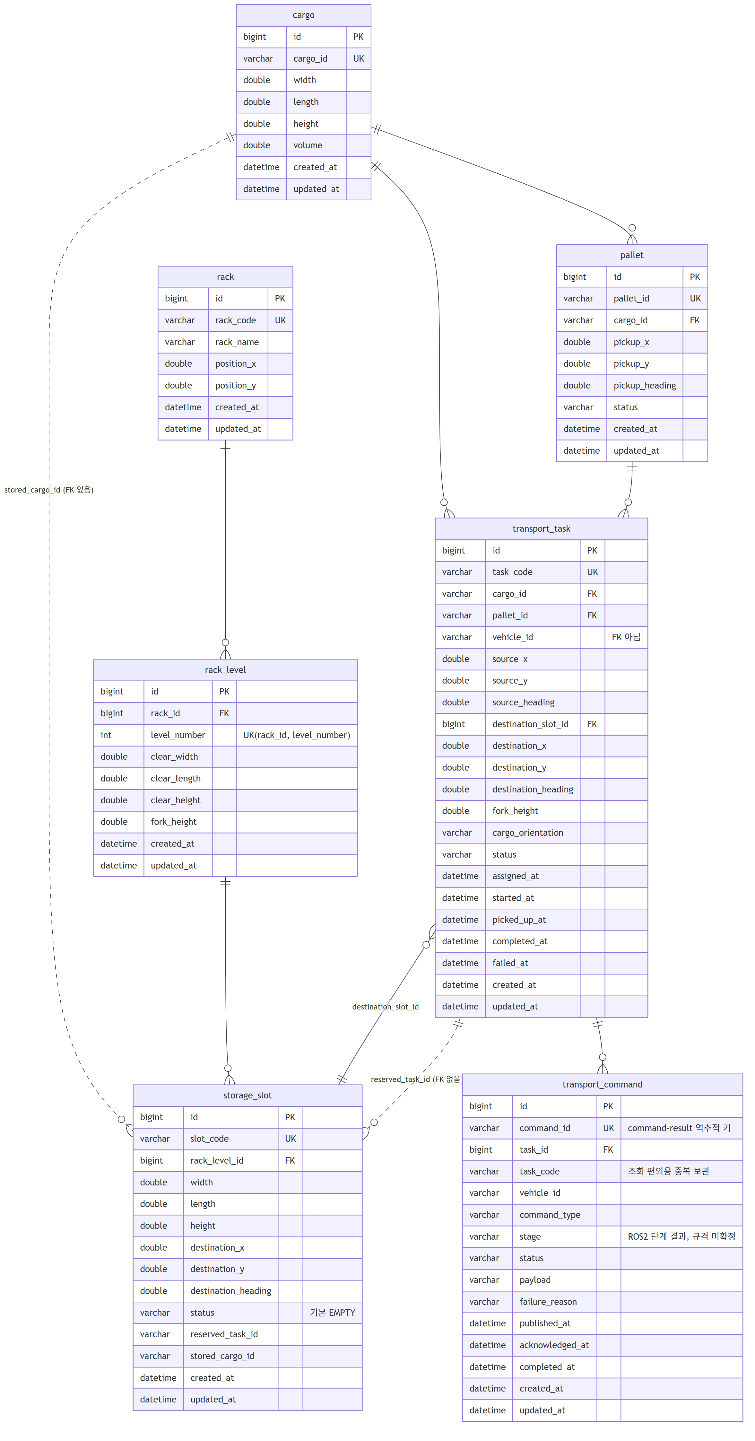
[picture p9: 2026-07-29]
docs/backend-db/erd/erd-05-warehouse.png

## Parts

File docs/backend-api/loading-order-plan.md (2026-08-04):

# 적재 순서 계획

## 목적

대기 중인 운반 작업 가운데 다음에 처리할 화물을 결정한다. MVP는 화물을 받는 위치와 측정 위치가
한 곳으로 고정되어 있고 한 번에 한 대의 지게차만 진입할 수 있는 통제된 환경을 전제로 한다.

이 문서에서 상차는 고정 위치의 화물을 지게차가 들어 올리는 과정이고, 하차는 추천된 적재 위치에
화물을 내려놓는 과정이다. 창고에서 화물을 꺼내 출고 지점으로 옮기는 역방향 출고 작업은 현재 범위에
포함하지 않는다.

## 현재 데이터와 제약

순서 계획에 사용하는 현재 데이터는 다음과 같다.

| 데이터 | 용도 |
|---|---|
| `transport_task.status` | 대기·진행·종료 작업 구분 |
| `transport_task.created_at` | 대기 순서 판단 |
| `transport_task.id` | 생성 시각이 같을 때의 최종 정렬 기준 |
| `transport_task.vehicle_id` | 작업이 배정된 차량 확인 |
| `vehicle.active` | 사용 가능한 차량 확인 |
| `vehicle_current_status.status` | `IDLE` 차량만 선택 |
| `station_state` | 측정 위치 점유 여부 확인 |
| `storage_slot.status` | 적재 위치 예약·점유 상태 확인 |

현재 `transport_task`에는 입고·출고 구분, 업무 우선순위, 마감 시각이 없다. 따라서 MVP에서는 임의의
가중치 점수식을 만들지 않고 생성 순서에 따른 선입선출을 사용한다.

또한 다음 동시성 제약을 유지한다.

- 한 화물에는 종료되지 않은 운반 작업을 하나만 생성한다.
- 한 차량에는 활성 운반 작업을 하나만 배정한다.
- `MOVING_TO_PICKUP` 또는 `MEASURING` 작업은 전체 시스템에서 하나만 허용한다.
- 적재 위치는 `EMPTY → RESERVED` 조건부 갱신으로 한 작업만 예약한다.

## MVP 순서 결정 규칙

다음 조건을 만족하는 작업만 순서 결정 대상이다.

```text
transport_task.status == PENDING
```

처리 순서는 다음 정렬식으로 결정한다.

```text
ORDER BY created_at ASC, id ASC
```

즉 가장 오래 기다린 작업을 먼저 처리한다. `id`는 동일한 시각에 생성된 작업도 항상 같은 순서로
결정하기 위한 보조 기준이다.

자동 매칭은 1초마다 실행하며 다음 조건을 모두 만족할 때 한 건만 처리한다.

1. 가장 오래된 `PENDING` 작업이 있다.
2. `active=true`이고 현재 상태가 `IDLE`인 차량이 있다.
3. 해당 차량에 다른 활성 작업이 없다.

조건을 만족하지 않으면 다음 주기에 다시 확인한다. 한 주기에는 하나만 배정하므로 여러 차량이 비어
있어도 작업은 1초 간격으로 차례대로 `ASSIGNED`가 된다.

자동 매칭은 차량 배정까지만 수행하며 MOVE 명령은 발행하지 않는다. 측정 위치 MOVE를 시작할 때는
기존 `VehicleCommandService`가 `MOVING_TO_PICKUP`, `MEASURING` 작업이 없는지 확인하므로 측정 차선에는
계속 최대 한 대만 진입한다.

## 처리 흐름

```text
PENDING 작업 조회
  → 가장 오래된 작업 선택
  → IDLE 차량 배정
  → 기존 MOVE 명령 대기
  → 고정 측정 위치 MOVE
  → 이전 측정 세션 해제 대기
  → 화물 측정
  → 적재 가능 여부 확인
  → 적재 위치 선택·예약
  → 화물 상차
  → 적재 위치로 이동
  → 화물 하차
  → 작업 완료
  → 다음 PENDING 작업 처리
```

작업 상태는 기존 상태 전이를 그대로 사용한다.

```text
PENDING → ASSIGNED → MOVING_TO_PICKUP → MEASURING → PICKING_UP
        → TRANSPORTING → PLACING → COMPLETED
```

- 측정 결과가 부적합하거나 빈 적재 위치가 없으면 `FAILED`로 종료한다.
- 이동 또는 측정 TTL이 만료돼도 `FAILED`로 종료한다.
- 목적지 예약 후 실패·취소되면 해당 위치를 다시 `EMPTY`로 반환한다.
- 실패한 작업 때문에 다음 작업을 막지 않으며, 종료 처리 후 다음 `PENDING` 작업을 선택한다.
- 발행된 측정 요청과 실패한 측정은 자동 재시도하지 않는다. 다만 이전 세션 점유 중에는 요청을 아직
  발행하지 않고 1초마다 설비 상태만 다시 확인한다.

## 적재 위치 선택과의 관계

적재 순서 계획은 어떤 화물을 먼저 처리할지만 결정한다. 실제 목적지는 측정이 끝난 뒤
`optimal-placement.md`의 규칙으로 선택한다.

따라서 작업 순서 산정 시에는 화물 높이나 목적지 이동 거리를 사용하지 않는다. 측정 전에는 화물 높이와
목적지 적재 위치가 아직 정해지지 않기 때문이다.

적재 위치 추천은 다음 순서로 수행한다.

1. 안전 조건과 높이 조건을 만족하는 `EMPTY` 위치 검색
2. 남는 높이가 가장 작은 위치 선택
3. 조건이 같으면 Nav2 이동 거리 사용
4. 거리도 같거나 없으면 `slotCode` 오름차순

## 권장 구현 위치

MVP 자동 스케줄러는 다음 구조로 구현한다.

| 구성 요소 | 역할 |
|---|---|
| `TransportSchedulingScheduler` | 1초 간격으로 자동 매칭 실행 |
| `TransportSchedulingService` | 다음 대기 작업과 사용 가능한 차량을 한 건씩 매칭 |
| `TransportTaskMapper` | 가장 오래된 `PENDING` 작업 조회 |
| `VehicleCurrentStatusMapper` | 사용 가능한 `IDLE` 차량 조회 |
| `TransportTaskService` | 기존 조건부 갱신으로 `PENDING → ASSIGNED` 처리 |

조회 직후 다른 요청이 먼저 작업이나 차량을 배정할 수 있으므로 기존 `TransportTaskService.assign()`의
조건부 `PENDING → ASSIGNED` 갱신 결과가 1건인지 최종 확인한다. 경합으로 배정에 실패하면 다음 1초
주기에 최신 상태를 다시 조회한다.

현재 스키마만으로 MVP를 구현할 수 있으므로 컬럼 추가는 필요하지 않다.

## 완료 조건

- 여러 `PENDING` 작업이 있으면 `created_at`, `id` 오름차순으로 처리된다.
- 측정 위치로 두 대가 동시에 이동하지 않는다.
- 한 차량에 두 개의 활성 작업이 배정되지 않는다.
- 실패·취소된 작업이 다음 작업의 실행을 막지 않는다.
- 적재 위치 예약 충돌이 발생하면 한 작업만 예약에 성공한다.
- 같은 입력 상태에서는 항상 같은 다음 작업이 선택된다.

## MVP 이후 확장

출고와 긴급 작업을 함께 최적화하려면 현재 스키마만으로는 부족하다. 실제 요구가 확정된 뒤 다음 정보를
추가한다.

- 작업 유형: `INBOUND`, `OUTBOUND`
- 업무 우선순위와 출고 마감 시각
- 출고 작업의 원본 적재 위치와 최종 하차 위치
- Nav2 예상 이동 거리 또는 경로 비용
- 통로 혼잡도와 다른 차량의 예약 경로

이 데이터가 추가되면 마감 임박도, 대기 시간, 이동 거리, 재배치 횟수를 조합한 우선순위 점수로
확장할 수 있다. 대기 시간이 길수록 점수를 높이는 aging 규칙을 함께 적용해 낮은 우선순위 작업이
무기한 밀리지 않도록 한다.

## 관련 파일

- 적재 위치 추천: `docs/backend-api/optimal-placement.md`
- 적재 공간 관리: `docs/backend-api/storage-space-recognition.md`
- 작업 상태: `src/main/java/com/fast/backend/transport/domain/TaskStatus.java`
- 작업 서비스: `src/main/java/com/fast/backend/transport/service/TransportTaskService.java`
- 자동 매칭: `src/main/java/com/fast/backend/transport/service/TransportSchedulingService.java`
- 주기 실행: `src/main/java/com/fast/backend/transport/service/TransportSchedulingScheduler.java`
- 작업 Mapper: `src/main/resources/mapper/TransportTaskMapper.xml`
- 실행 스키마: `src/main/resources/db/schema.sql`

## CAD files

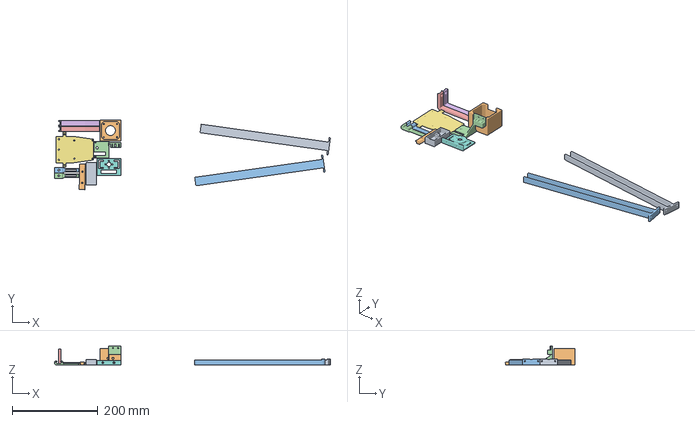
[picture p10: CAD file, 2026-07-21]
3d_model/포크_구성 1_덥개 탑.3mf
643.7 x 162.2 x 43.6 mm
본체1 x 12

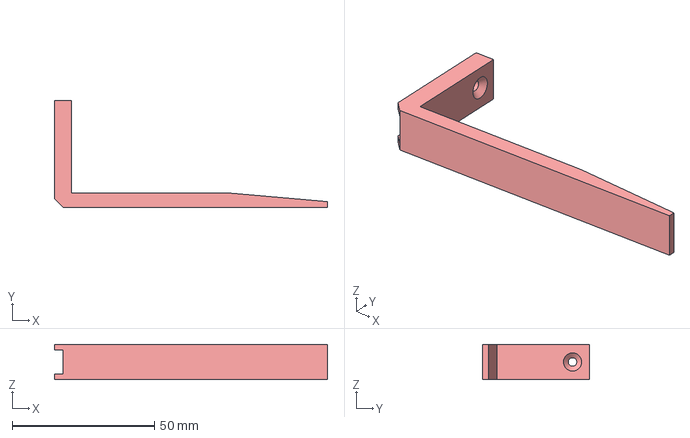
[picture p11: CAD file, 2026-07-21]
3d_model/포크_구성 1_포크 바텀R.3mf
96.0 x 37.5 x 12.4 mm

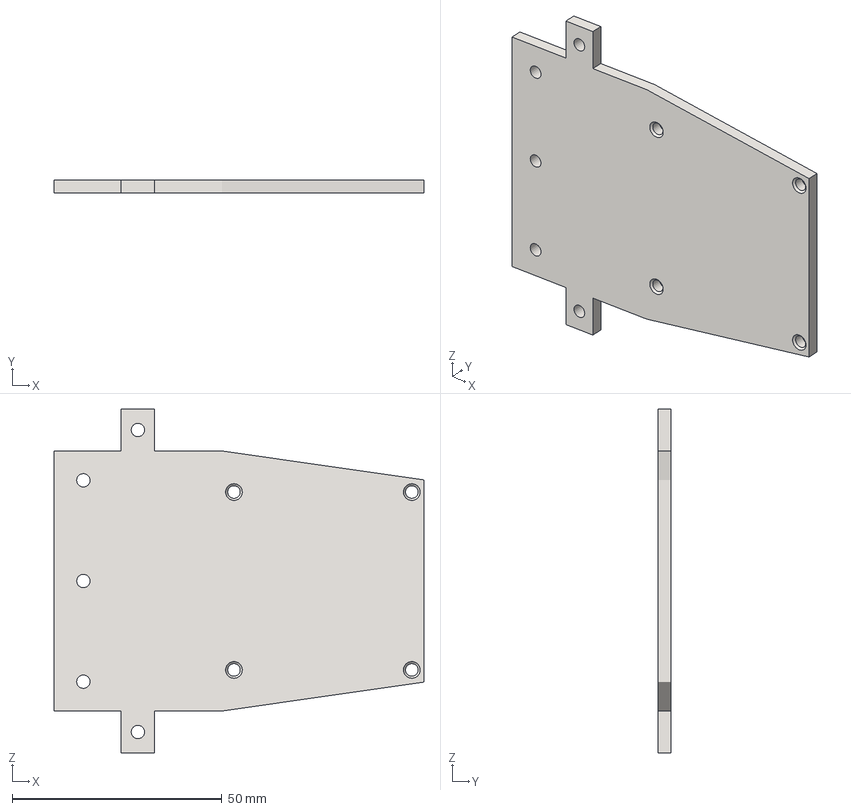
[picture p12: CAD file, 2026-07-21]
3d_model/포크_구성 1_고정부 하단.3mf
88.2 x 3.00 x 82.0 mm

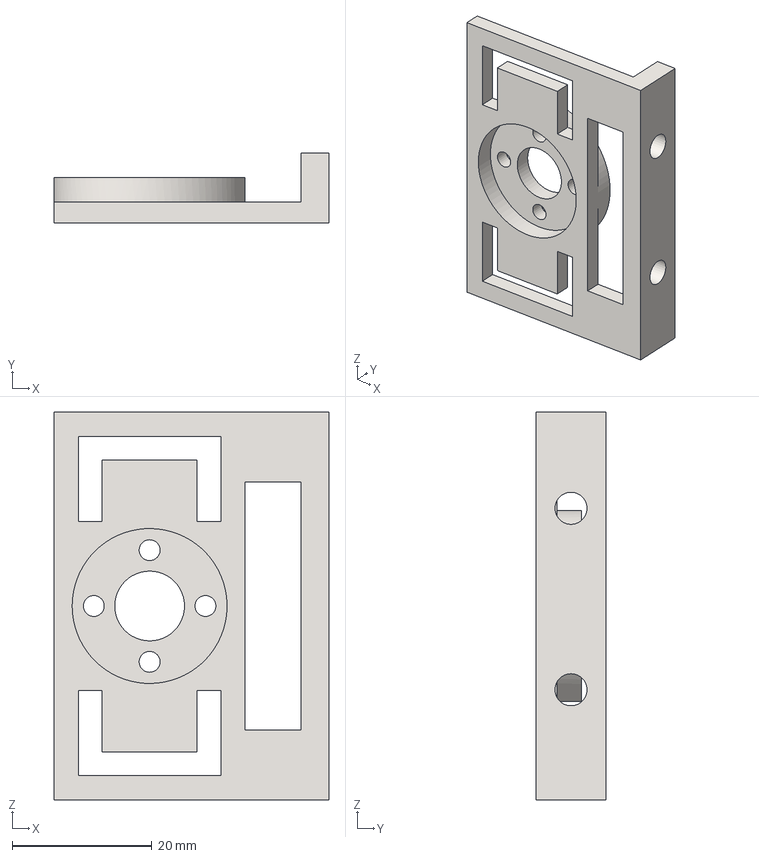
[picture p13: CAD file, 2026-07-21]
3d_model/포크_구성 1_캐리지.3mf
39.4 x 10.0 x 55.6 mm

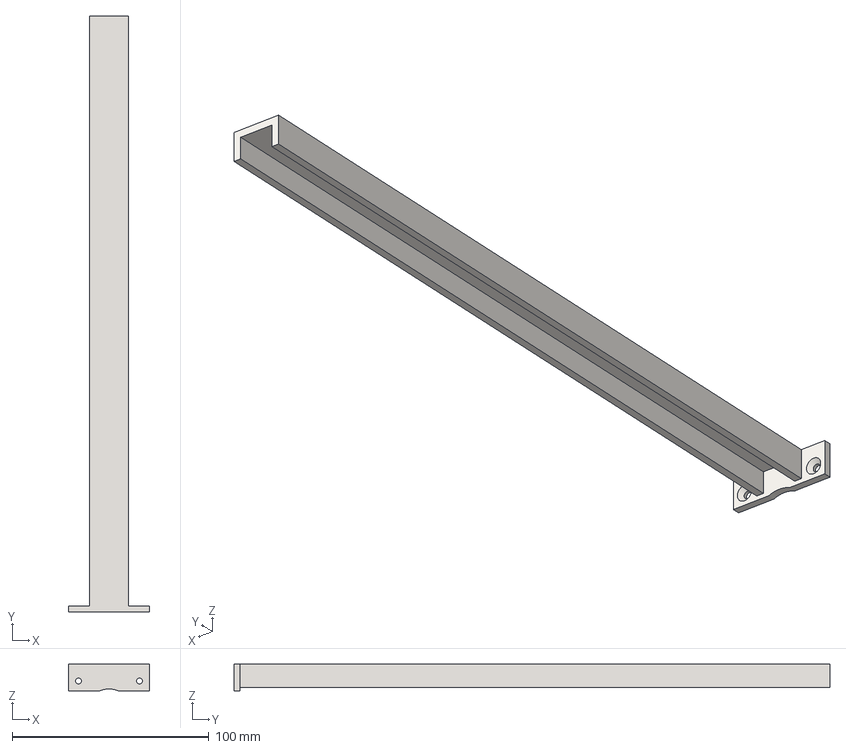
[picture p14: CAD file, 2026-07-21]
3d_model/포크_구성 1_기둥R.3mf
41.0 x 303.0 x 13.6 mm

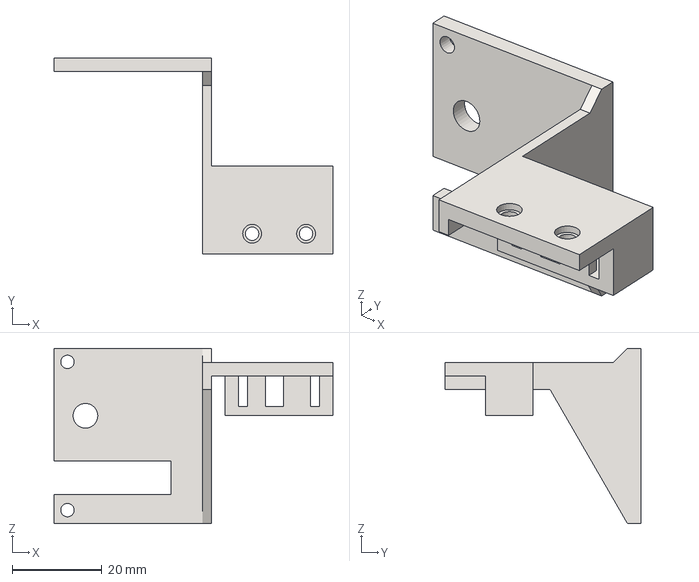
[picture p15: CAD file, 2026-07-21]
3d_model/포크_구성 1_고정부 상단.3mf
62.1 x 43.6 x 39.0 mm

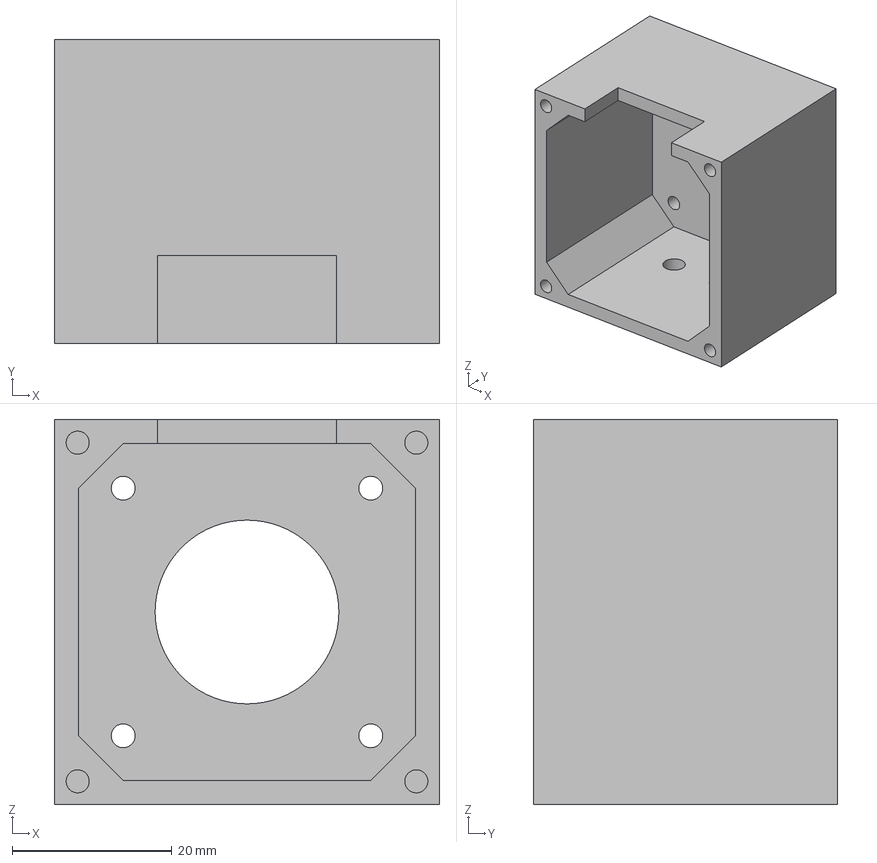
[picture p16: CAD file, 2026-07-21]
3d_model/포크_구성 1_스텝 커버.3mf
48.2 x 38.0 x 48.2 mm

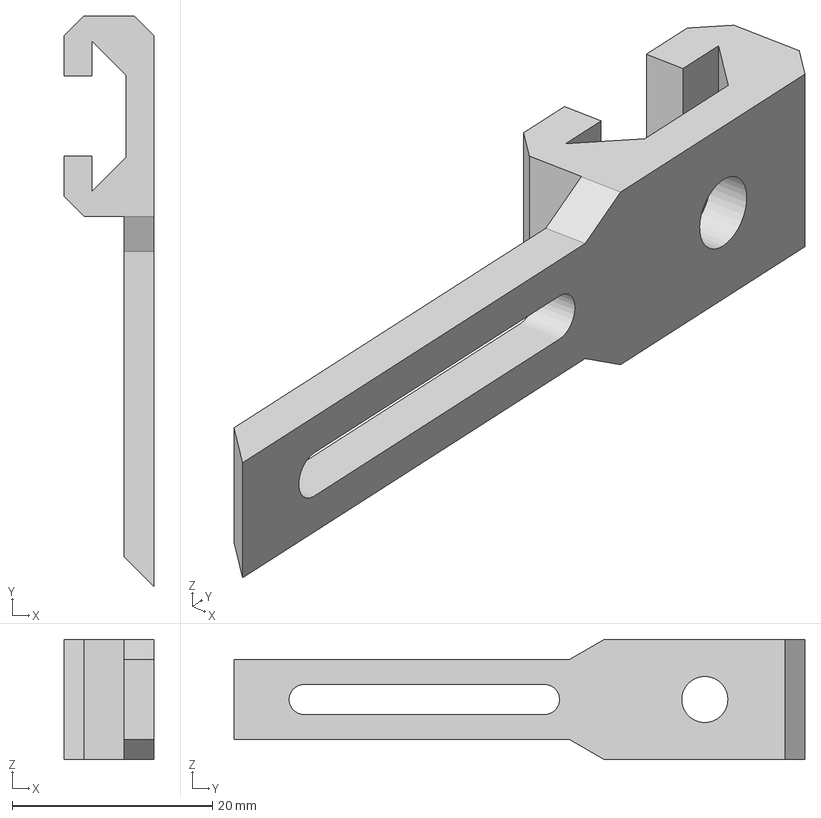
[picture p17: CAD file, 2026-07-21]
3d_model/포크_구성 1_포크 탑R.3mf
9.00 x 57.0 x 12.0 mm

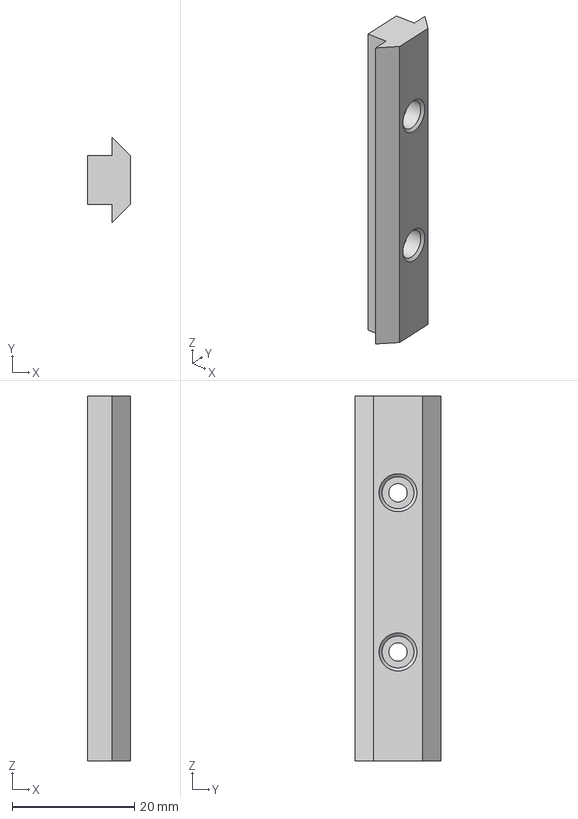
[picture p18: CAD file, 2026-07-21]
3d_model/포크_구성 1_피카티니.3mf
7.00 x 14.0 x 59.6 mm

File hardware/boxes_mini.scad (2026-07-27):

// 미니어처 화물 박스 (실물 /10) — 프린트용
// 단위 mm. OpenSCAD F6(렌더) 후 F7(Export STL).
// 편하중은 기하 중심으로 판정 → 솔리드로 뽑아도 무방(shell=0).

scale_k = 10;          // 축척비

// 실물 치수 mm [W, D, H]
box_2   = [184, 267, 152];   // 2호  x1
box_2_1 = [342, 255, 105];   // 2-1호 x2

shell   = 0;           // 0 = 솔리드. >0이면 그 두께(mm)로 속 빈 셸(필라멘트 절감)
gap     = 8;           // 베드에서 부품 간 간격

module mini_box(real_mm) {
  d = [ for (v = real_mm) v/scale_k ];
  if (shell <= 0)
    cube(d);
  else
    difference() {
      cube(d);
      translate([shell, shell, shell])
        cube([d[0]-2*shell, d[1]-2*shell, d[2]-2*shell]); // 윗면 열린 셸
    }
}

// 한 베드에 3개(2호 1 + 2-1호 2) 나란히 배치
mini_box(box_2);
translate([box_2[0]/scale_k + gap, 0, 0]) mini_box(box_2_1);
translate([box_2[0]/scale_k + box_2_1[0]/scale_k + 2*gap, 0, 0]) mini_box(box_2_1);

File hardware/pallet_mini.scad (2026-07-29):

// 미니어처 T-11 파렛트 — 실물 치수 1/10 (faithful scale)
// 포크가 1/10 실물 파렛트 기준으로 설계됨 → 실물을 그대로 축소.
// 단위 mm. OpenSCAD F6(렌더) 후 F7(Export STL).
//
// ✅ 2026-07-29 실측 반영. 이전 기본값(높이 120·블록 140)은 미검증 표준 근사치였고
//    실물과 달랐다 — 그대로 재출력하면 개구부가 7.6mm로 나와 실물(9.5mm)과 어긋난다.

k = 10;   // 축척비

/* ===== 실물 파렛트 치수(mm) — 2026-07-29 실측 반영 ===== */
R_foot_x   = 1100;   // 가로
R_foot_y   = 1100;   // 세로
R_height   = 140;    // 전체 높이 (미니 14mm 실측)
R_top_deck = 22.5;   // 상판 두께  ┐ 합 45mm는 (높이 140 − 개구 95)에서 역산.
R_bot_deck = 22.5;   // 하판 두께  ┘ 상·하 분배는 실측하지 않아 균등 가정.
R_block    = 133;    // 다리 블록 한 변 — 개구 폭 35mm·중심 간격 48.3mm에서 역산(직접 실측 아님)
/* ===================================================== */

/* ===== 미니어처 지게차 포크 실측(mm) — fit 검증용 ===== */
F_thick = 5;      // 포크 수직 두께(뿌리) → 통로 높이가 이보다 커야 함
                  // ⚠️ 실물 포크는 끝으로 갈수록 얇아지는 테이퍼다. 이 모델엔 반영돼 있지 않아
                  //    진입 초기의 실제 여유는 도면보다 넉넉하다(오픈루프 진입의 근거).
F_width = 12;     // 포크 너비       → 통로 폭이 이보다 커야 함
F_gap   = 40;     // 두 포크 사이 최대 간격(0~40 가변)
/* ==================================================== */

// --- /10 환산 (미니어처) ---
foot_x = R_foot_x  / k;
foot_y = R_foot_y  / k;
height = R_height  / k;
topd   = R_top_deck/ k;
botd   = R_bot_deck/ k;
blk    = R_block   / k;
open_h = height - topd - botd;        // 포크 통로(구멍) 높이  ← 이게 포크 두께보다 커야 함

module deck(z, t) translate([0,0,z]) cube([foot_x, foot_y, t]);
module blocks(z)                       // 3x3 다리 → 4방향 포크 진입
  for (x = [0, foot_x/2 - blk/2, foot_x - blk])
    for (y = [0, foot_y/2 - blk/2, foot_y - blk])
      translate([x, y, z]) cube([blk, blk, open_h]);

if (botd > 0) deck(0, botd);           // 하판
blocks(botd);                          // 다리
deck(botd + open_h, topd);             // 상판

// --- fit 검증 (콘솔에 출력) ---
chan_w  = (foot_x - 3*blk) / 2;        // 포크 통로 폭
chan_sp = (foot_x - blk) / 2;          // 두 통로 중심 간격
fork_cc_max = F_gap + F_width;         // 포크 최대 중심거리 (간격 0 → 최소 = F_width)
echo(str("미니 파렛트: ", foot_x, "x", foot_y, "x", height, "mm"));
echo(str("통로 높이 open_h = ", open_h, "mm  vs  포크두께 ", F_thick,
         "mm  → ", open_h > F_thick ? "OK" : "!! 안 들어감"));
echo(str("통로 폭 chan_w = ", chan_w, "mm  vs  포크너비 ", F_width,
         "mm  → ", chan_w > F_width ? "OK" : "!! 안 들어감"));
echo(str("통로 중심간격 = ", chan_sp, "mm  vs  포크 중심거리 ", F_width, "~", fork_cc_max,
         "mm  → ", (chan_sp >= F_width && chan_sp <= fork_cc_max) ? "OK" : "!! 간격 조정 필요"));

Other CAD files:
3d_model/포크_구성 1_기둥L.3mf
3d_model/포크_구성 1_포크 탑L.3mf
3d_model/포크_구성 1_포크 바텀L.3mf

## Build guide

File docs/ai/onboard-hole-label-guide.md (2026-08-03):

# 온보드 포크 정렬 — `hole` 라벨 가이드

> 대상: S15P11A304-144 미니어처 데이터셋 촬영·라벨링 (온보드 -s 포크 정렬 비전용)
> 확정일: 2026-07-29 · 관련: 145(파인튜닝) · 152(정렬 제어 루프) · 153(블라인드 진입) · 154(성공·실패 판정)

## 1. 왜 클래스로 검출하나

포크 정렬 사다리의 **Level 2를 고전 CV가 아니라 학습 클래스로** 간다.

- 고전 CV로 파렛트를 다루려던 시도는 이미 실패했다 — `pallet_autolabel` 최고 7/40, 가림 상황에서 무력.
- 검은 플라스틱 파렛트의 구멍은 **명암 대비가 낮아** 임계·에지 기반이 특히 불리하다. 구멍 안쪽이 어둡고 파렛트 본체도 어둡다.
- 어차피 이 촬영분으로 온보드 -s를 파인튜닝하므로 **클래스 하나 늘리는 한계비용은 라벨링뿐**이다.

사다리: bbox 역산(L1) → **구멍 검출 클래스(L2, 채택)** → 키포인트(L3) → ArUco(L4)

⚠️ **클래스 구성은 배포처별로 다르다.** 온보드 -s는 **`pallet`·`hole`**, 스테이션 -m은 **`box`·`pallet`** — 둘 다 2클래스지만 **구성이 다르다**. 스테이션은 구멍을 볼 이유가 없고, 현역 exp8 계보를 건드리면 검증 끝난 치수(0.66mm)·편하중 KPI를 다시 태워야 한다.

> **온보드 `box` 폐기 (2026-07-30)**: 당초 온보드를 3클래스(box·pallet·hole)로 계획했으나,
> exp8 프리라벨이 흰 파렛트를 box로 오인해(장당 2.4개, 파렛트 오인 22%) pallet 검출(G2)을
> 해쳐서 **box를 뺐다.** `onboard_eval.json` 어노테이션도 `pallet 105` · `hole 221` ·
> **box 0건**이다. `label_onboard.py`의 `CLASSES`에 box(id 1)가 슬롯으로 남아 있지만
> 비어 있다 — 이 잔재 때문에 "3클래스" 기술이 문서에 남아 있었다(2026-08-03 정정).

## 2. 실측 치수 (2026-07-29)

| 항목 | 값 | 비고 |
|---|---|---|
| 미니 파렛트 | 110 × 110 × **14** mm | 높이는 실측. SCAD 기본값(12mm)은 미검증 표준 근사치였다 |
| **개구부(구멍)** | **35 × 9.5 mm** | 종횡비 약 **3.7 : 1** — 납작하다 |
| 통로 중심 간격 | **48~49 mm** | |
| 포크 | 두께 **5 mm**(뿌리) · 너비 **12 mm** | 끝으로 갈수록 얇아지는 **테이퍼** |

**여유가 가로·세로에서 5배 차이 난다.**

- 가로: (35 − 12) / 2 = **±11.5 mm**
- 세로: (9.5 − 5) / 2 = **±2.25 mm** ← 뿌리 기준, 테이퍼라 진입 시작은 더 넉넉

→ **비전(`hole`)은 가로 x와 요(yaw)를 책임진다.** 높이(세로)는 ±2.25mm라 카메라로 잡기엔 비싸고, **스텝모터 캘리브레이션 + 리밋 스위치**(FR-303-4)가 담당하는 것이 맞다.
→ 테이퍼는 **153(블라인드 구간 오픈루프 진입)의 물리적 근거**다. 끝을 걸치고 밀어 넣으면 상하로 자기정렬된다.

## 3. 라벨 규약

### ① 구멍 하나가 인스턴스 하나 — 묶지 않는다

포크가 2개고, 정렬은 두 구멍 중심선에 두 포크를 맞추는 문제다. 하나로 묶으면 중심은 알아도 **간격을 모른다.** 더 중요한 건 비스듬히 볼 때 **먼 쪽 구멍이 좁게 보이는 폭 비가 요(yaw) 신호**라는 점이다 — 묶으면 사라진다.

### ② modal — 보이는 대로 그린다 (파렛트의 amodal 규약을 따르지 않는다)

클래스마다 규약이 다른 이유는 **하류가 묻는 질문이 다르기 때문**이다.

| 클래스 | 규약 | 하류가 묻는 것 |
|---|---|---|
| `pallet` | **amodal** (가려진 부분까지 전체 범위) | 파렛트의 실제 중심·상단은 어디인가 (편하중·on_pallet·tilt) |
| `box` | modal | 보이는 화물은 어디 있나 |
| `hole` | **modal** | **여기에 포크를 꽂을 수 있나** |

가려진 구멍은 꽂을 수 없다. amodal로 그리면 화물이나 다른 파렛트에 막힌 구멍도 "열려 있다"고 가르치게 되고, 그 대가는 **포크가 박는 것**이다. 비용이 비대칭이므로 modal이 맞다.

### ③ 가로가 원래의 50% 미만으로 보이면 라벨하지 않는다

35mm × 50% = 17.5mm이고 포크 너비가 12mm다. 즉 **50%가 "여유 5.5mm 남은 진입 한계선"** 이라 경계로서 자연스럽다. 그 이하는 진입 대상이 아니므로 가르치지 않는다.

완전히 안 보이면 당연히 라벨 없음. 단 **`pallet`은 그대로 amodal로 그린다**(기존 규약 유지).

**화면 밖으로 잘린 파렛트는 예외다** — amodal은 *가려진* 부분을 채우는 규약이고, 프레임 경계는 가림이 아니다. COCO bbox는 이미지 좌표를 벗어날 수 없으므로 **경계에서 자른다**. 실제로 구간 5의 프레임 214는 파렛트가 오른쪽 화면 끝에서 잘려 있다. 온보드에서는 손실이 없다 — 잘린 파렛트는 접근 대상이 아니고, 진입면 선택은 보이는 구멍으로 하기 때문이다(§3-⑥). 파렛트의 실제 중심을 요구하는 하류(편하중)는 **스테이션 -m 쪽 관심사**이고 거기엔 이 규약이 적용되지 않는다.

### ④ 크기 하한은 **세로** 기준 — 원본 16px 미만 제외

종횡비가 3.7:1이라 **세로가 먼저 뭉개진다.** 가로 20px로 자르면 세로가 5px밖에 안 돼 RTMDet-s(최소 stride 8)에서 학습이 안 된다.

> 개구부 **세로가 원본(1280×800)에서 16px 미만**이면 라벨하지 않는다 (640 환산 8px).

이때 가로는 약 59px, 파렛트 전체는 약 185px이다. 포크 접근 뷰에서는 파렛트가 이보다 훨씬 크게 잡히므로 실촬영에 제약이 되지 않는다. 이 프레임은 `pallet`만 라벨한다.

### ⑤ 경계는 구조물 기준 — 그림자가 아니다

구멍은 어두워 경계가 번져 보인다. **상판 아랫면 ~ 하판 윗면, 좌우 다리 안쪽 면**이 만드는 실제 개구 사각형을 따른다. 그림자가 안쪽으로 퍼져 보여도 구조를 기준으로 그린다.

### ⑥ 비스듬히 볼 때 보이는 구멍은 **전부** 그린다

파렛트는 다리가 3×3이라 **네 면 모두 포크가 들어가고, 각 면에 구멍이 2개**씩 있다. 정면(0°)에서는 앞면 2개만 보이지만 **회전 45° 부근에서는 옆면 구멍까지 화면에 잡혀 최대 4개**가 된다. 촬영 변형 축에 회전 0~45°가 있으므로 이런 프레임이 다수 나온다.

**보이는 것을 전부 그린다.** 앞면 2개만 그리는 방식은 채택하지 않았다 —

> 그 방식은 라벨러에게 **사진만 봐서는 알 수 없는 것**을 요구한다. 어느 면으로 진입할지는 지게차가 어느 방향에서 접근하느냐에 달렸고, 그건 정지된 사진에 없는 정보다. 45° 근처에서 사람마다 다르게 판단하면 모델은 "어떤 구멍은 구멍이 아니다"라는 모순된 신호를 배운다.

대신 진입면 선택은 **런타임에** 한다(152): **두 구멍의 중심을 이은 선분이 더 길고 개구가 넓은 쪽**을 진입면으로 고른다. 정면에 가까울수록 구멍이 넓게 보이기 때문이다.

## 4. 클래스 id와 검수

```
box = 1, pallet = 2, hole = 3
```

기존 계보(box=1, pallet=2)를 유지하고 뒤에 붙인다.

**검수 자동 체크** — 라벨 검수기에 넣을 sanity check:

1. `hole` bbox는 **`pallet` bbox 안에 포함**돼야 한다
2. `hole` 종횡비가 1.5:1 미만이면 경고 (정상은 약 3.7:1, 너무 정사각이면 오라벨 의심)
3. 한 프레임의 `hole` 개수가 **5개 이상이면 경고** (구조상 최대 4개)
4. `pallet`이 없는데 `hole`만 있으면 오류

## 5. 카메라 설치 (2026-07-29 실측)

**해상도는 1280×800이 최대다.** 판매 스펙의 1280×960은 나오지 않는다 — 요청해도 조용히 800으로 떨어진다. 지원 모드는 640×480 · 800×600 · 1280×720 · **1280×800**(30fps). 노트북에서는 index 1이다(index 0은 내장 웹캠).

**내려다보는 각(θ)을 20° 이하로.** 구멍은 지면에서 2.25~11.75mm 구간의 얇은 슬롯이라, 위에서 내려다보면 개구가 `9.5 × cosθ`로 납작해진다.

| θ | 화면상 개구 높이 |
|---|---|
| 20° | 8.9mm (−6%) |
| 30° | 8.2mm (−13%) |
| 45° | 6.7mm (−29%) |

납작해질수록 §3-④의 세로 16px 하한에 먼저 걸린다. **카메라는 낮게, 광축은 수평에 가깝게** 단다. 높이 6cm면 거리 15cm에서 21°, 높이 12cm면 30cm에서 20°다.

**뒤집어 장착했다면 `--rotate180`을 쓴다.** 뒤집힌 채로 찍으면 ①사람이 뒤집힌 화면을 보고 라벨해야 하고 ②정립으로 라벨된 공개 데이터(LOCO `pallet`)와 방향이 어긋나며 ③"화물은 파렛트 위에 얹힌다" 같은 하류 기하 가정이 반대가 된다.

> ⚠️ **추론 경로에도 같은 회전을 넣어야 한다.** 한쪽만 돌리면 학습·추론 도메인이 정반대가 되고, 모델이 아무것도 못 잡는데 원인을 찾기 어려운 상태가 된다.

```
python src/station/shoot.py --out data/raw/onboard/train_20260729/b01 \
    --prefix onb --camera 1 --width 1280 --height 800 --rotate180 --burst 6
```

## 6. 촬영·라벨 체크리스트

- [ ] 뷰: **포크 접근 뷰(낮은 정면)** — 온보드 카메라 실제 장착 위치·높이 그대로
- [ ] train(300~500장)과 eval(100~150장)을 **촬영 단계부터 분리** (딴 날·딴 배치, 누수 차단)
- [ ] 변형 축: 위치(중앙/편심), **회전 0~45°**, 조명 3종, 배경 변형, 네거티브(빈 바닥·파렛트만)
- [ ] 프리라벨은 기존 -s로 `box`·`pallet`만. **`hole`은 사람이 처음부터 그린다** (모델이 모르는 클래스라 프리라벨이 없다)
- [ ] eval 셋은 최종 평가 전까지 열지 않는다

## 7. 알려진 한계

- 세로 여유 ±2.25mm는 **뿌리 기준**이다. 테이퍼 형상이 `pallet_mini.scad`에 모델링돼 있지 않아, 진입 초기의 실제 여유는 도면이 아니라 실물로만 확인된다.
- 다리 블록 치수(13.3mm)는 직접 잰 값이 아니라 **개구 폭 35mm·중심 간격 48~49mm에서 역산**한 값이다. 세 숫자가 서로 맞아떨어져 신뢰할 만하지만, 재출력 전에는 블록을 직접 재보는 것이 안전하다.

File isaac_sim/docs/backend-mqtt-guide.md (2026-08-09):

# 백엔드 MQTT 연동 안내 (E팀용)

작성 2026-08-05 · 작성자 F(디지털 트윈·관제 프론트)

시뮬레이터 쪽 MQTT 연동이 동작 확인까지 끝났습니다. 이 문서 하나로
**브로커 접속 → 토픽 → 페이로드 → 백엔드가 구현할 것** 까지 정리했습니다.

교통 규칙의 상세 알고리즘은 [traffic-rules-spec.md](traffic-rules-spec.md),
실물 차량(C팀) 규격은 [orin-pose-spec.md](orin-pose-spec.md) 를 봅니다.

---

## 0. 먼저 — 오늘 바뀐 것 (기존 구현이 있다면 확인 필요)

| # | 항목 | 이전 | **현재** | 영향 |
|---|---|---|---|---|
| 1 | 시뮬 차량 ID | `sim01`, `sim02` | **`sim02`, `sim03`** | **깨짐** — 토픽 이름이 바뀝니다 |
| 2 | 좌표 단위 | 실물 m (0~2, 0~3) | **시뮬 좌표 (0~20, 0~30)** | **깨짐** — 값이 10배 |
| 3 | `cargo` 필드 | 없음 | 추가 | 호환 (무시 가능) |
| 4 | `state` 값 | — | `LOADING`, `UNLOADING` 추가 | 호환 (미지의 값 처리만) |

### 1. 차량 ID 를 프림 번호와 맞췄습니다

Isaac 씬의 프림 이름과 MQTT ID 가 하나씩 어긋나 혼란이 있어 정리했습니다.

| Isaac 프림 | MQTT vehicleId | 비고 |
|---|---|---|
| SIM_F02 | **`sim02`** | 이전 `sim01` |
| SIM_F03 | **`sim03`** | 이전 `sim02` |
| REAL_F01 (실물 오린카) | `fk01` | 변경 없음 |

### 2. 좌표는 시뮬 좌표계로 통일했습니다

**MQTT 위의 모든 좌표는 시뮬레이션 좌표계(20 × 30)입니다.**
실물 세트장은 그 1/10 인 2 × 3 m 이고, **변환은 실물 차량(오린카)이 자기 쪽에서**
합니다 (보낼 때 ×10, 받을 때 ÷10).

백엔드는 **아무 변환도 하지 않습니다.** 받은 좌표를 그대로 쓰고,
목표도 시뮬 좌표로 보내면 됩니다.

```
           x: 0 ~ 20.0      y: 0 ~ 30.0      yaw: -π ~ +π (라디안, 반시계 +)
원점 (0,0) = 창고 왼쪽 아래 모서리
```

---

## 1. 브로커 접속

| 항목 | 값 |
|---|---|
| 호스트 | `i15a304.p.ssafy.io` (3.38.178.143) |
| 포트 | **8883 — TLS 전용**. 1883 은 닫혀 있습니다 |
| 인증 | 아이디 / 비밀번호 (별도 전달) |
| 인증서 | 자체 서명 CA `FAST-MQTT-CA` |

인증서 CN 이 호스트명이 아니라 **IP** 라서, 호스트명으로 접속하면 hostname
검증에 실패합니다. 두 가지 중 하나로 처리합니다.

- **권장** — CA 파일(`fast-mqtt-ca.crt`, F팀이 전달)을 truststore 에 넣고
  hostname 검증만 끄기
- **임시** — 인증서 검증 생략 (개발 중에만)

Spring 예시 (Eclipse Paho):

```java
MqttConnectOptions opts = new MqttConnectOptions();
opts.setUserName("아이디");
opts.setPassword("비번".toCharArray());
opts.setAutomaticReconnect(true);
opts.setCleanSession(true);

// CA 를 넣은 truststore 사용 + hostname 검증만 끄기
SSLSocketFactory sf = SslUtil.getSocketFactory("classpath:fast-mqtt-ca.crt");
opts.setSocketFactory(sf);
opts.setHttpsHostnameVerificationEnabled(false);   // CN 이 IP 라서 필요

MqttClient client = new MqttClient("ssl://i15a304.p.ssafy.io:8883",
                                   "fast-backend", new MemoryPersistence());
client.connect(opts);
```

> 근본 해결은 인증서를 **SAN 에 도메인을 넣어 재발급**하는 것입니다.
> 브로커를 운영하는 쪽에서 가능하면 그렇게 하는 편이 낫습니다.

---

## 2. 토픽 한눈에

`{id}` = `sim02` | `sim03` | `fk01`

### 백엔드가 **구독**할 것 (차량 → 관제)

| 토픽 | 주기 | 내용 |
|---|---|---|
| `fast/v1/vehicle/{id}/telemetry` | 10 Hz | 위치·속도·포크·적재·상태 |
| `fast/v1/vehicle/{id}/event` | 변화 시 | 상태 전이, 오류 |
| `forklift/{id}/arrived` | 도착 시 | 입고 바이 도착 (AI 측정 트리거) |

> `arrived` 만 접두사가 `forklift/` 로 다릅니다. 이전 합의를 그대로 둔 것이라,
> 통일이 필요하면 알려주세요.

### 백엔드가 **발행**할 것 (관제 → 차량)

| 토픽 | 내용 |
|---|---|
| `fast/v1/vehicle/{id}/task` | 목적지 지시 |
| `fast/v1/vehicle/{id}/control` | 정지 / 재개 / 작업취소 |
| `fast/v1/vehicle/{id}/cargo` | 화물 적재·랙 적재 지시 |
| `fast/v1/control/all` | 전체 제어 |
| `fast/v1/sim/camera` | 시뮬 화면 시점 전환 |

---

## 2.5 빠른 시작 — 멈추고 움직이기

가장 먼저 해보면 좋은 네 가지입니다. 그대로 복사해 쓰면 됩니다.
(`<아이디>` `<비번>` 은 별도 전달, `fast-mqtt-ca.crt` 도 함께 드립니다)

```bash
B="-h i15a304.p.ssafy.io -p 8883 -u <아이디> -P <비번> --cafile fast-mqtt-ca.crt --insecure"
```

### ① 지금 어디 있나 (구독)

```bash
mosquitto_sub $B -t 'fast/v1/vehicle/+/telemetry' -v
```

### ② 멈춰라

```bash
mosquitto_pub $B -t 'fast/v1/vehicle/sim02/control' -m '{"command":"ESTOP"}'
```

즉시 멈추고, telemetry 의 `state` 가 `ESTOPPED` 로 바뀝니다.
목표 취소만 하는 게 아니라 속도 0 을 20 Hz 로 계속 눌러서 붙잡습니다.

### ③ 다시 움직여라

```bash
mosquitto_pub $B -t 'fast/v1/vehicle/sim02/control' -m '{"command":"RESUME"}'
```

`state` 가 `MOVING` / `IDLE` 로 돌아옵니다.

### ④ 저기로 가라

```bash
mosquitto_pub $B -t 'fast/v1/vehicle/sim02/task' \
  -m '{"taskId":"T-1","x":16.5,"y":5.0,"yaw":0.0}'
```

좌표는 **시뮬 좌표**(0~20 × 0~30). 위 예시는 입고 바이입니다.

### 전체 정지 / 해제

```bash
mosquitto_pub $B -t 'fast/v1/control/all' -m '{"command":"ESTOP"}'
mosquitto_pub $B -t 'fast/v1/control/all' -m '{"command":"RESUME"}'
```

### Java (Paho) 로는

```java
// 멈춤
client.publish("fast/v1/vehicle/sim02/control",
        "{\"command\":\"ESTOP\"}".getBytes(StandardCharsets.UTF_8), 1, false);

// 재개
client.publish("fast/v1/vehicle/sim02/control",
        "{\"command\":\"RESUME\"}".getBytes(StandardCharsets.UTF_8), 1, false);

// 이동
String task = """
    {"taskId":"T-1","x":16.5,"y":5.0,"yaw":0.0}
    """;
client.publish("fast/v1/vehicle/sim02/task",
        task.getBytes(StandardCharsets.UTF_8), 1, false);
```

QoS 는 명령류 **1**, telemetry 구독은 **0** 을 권합니다.

### 주의

- **정지 중에는 `task` 가 무시됩니다.** 먼저 `RESUME` 를 보내세요.
- F팀 데모가 돌고 있으면 데모도 목표를 보내므로 서로 밀어냅니다.
  목적지 지시를 시험할 때는 F팀에 데모를 꺼 달라고 하세요.
  **정지/재개는 데모가 돌아도 그대로 먹습니다** (데모가 관제 정지를 존중하도록
  되어 있습니다).

---

## 3. telemetry (구독)

```json
{
  "vehicleId": "sim02",
  "ts": 1785000000000,
  "pose":     { "x": 12.34, "y": 5.67, "yaw": 1.5708 },
  "velocity": { "linear": 1.0, "angular": 0.0 },
  "forkHeight": 1.325,
  "loaded": true,
  "cargoId": "C0007",
  "cargo":  { "id": "C0007", "w": 0.75, "d": 0.91, "h": 1.11 },
  "busy": true,
  "step": "dock",
  "state": "UNLOADING",
  "taskId": "T-1042",
  "battery": 100.0
}
```

| 필드 | 형 | 설명 |
|---|---|---|
| `vehicleId` | string | `sim02` / `sim03` / `fk01` |
| `ts` | int | 유닉스 **밀리초** |
| `pose.x` `pose.y` | float | **시뮬 좌표** 0~20 / 0~30 |
| `pose.yaw` | float | 라디안, −π~+π, 반시계 + |
| `velocity.linear` | float | m/s (시뮬 단위). 후진 음수 |
| `velocity.angular` | float | rad/s |
| `forkHeight` | float | 포크 높이 (시뮬 단위). 바닥 0 |
| `loaded` | bool | 화물 소지 여부 |
| `cargoId` | string \| null | 화물 식별자 |
| **`cargo`** | object \| null | **신규** — 화물 크기. 미소지 시 `null` |
| `cargo.w` `d` `h` | float | 가로·세로·**전체 높이**(파레트 포함) |
| **`busy`** | bool | **절차(정렬·도킹·적재) 수행 중인가.** 단계 전환은 이걸로 판정 |
| **`step`** | string | 지금 수행 중인 절차 이름 (`align` `fork` `dock` `place` …) |
| `state` | string | 아래 표 |
| `taskId` | string \| null | 수행 중인 task |
| `battery` | float | 0~100 |

### `state` 값

| 값 | 뜻 | 관제 화면 표시 예 |
|---|---|---|
| `IDLE` | 정지, 명령 대기 | 대기 |
| `MOVING` | 주행 중 | 이동 중 |
| **`LOADING`** | **입고 바이에서 화물 받는 중** (신규) | 적재 중 |
| **`UNLOADING`** | **랙에 내려놓는 절차 진행 중** (신규) | 하역 중 |
| `LIFTING` / `LOWERING` | 포크 상승 / 하강 | 포크 동작 |
| `HOLDING` | 관제가 멈춤(HOLD) | 대기(관제) |
| `ESTOPPED` | 비상정지 | 비상정지 |
| `ERROR` | 고장 | 오류 |

`LOADING` / `UNLOADING` 은 **포크가 움직이지 않는 구간까지 포함**합니다.
시뮬은 바이에서 화물이 즉시 생성되어 포크 동작이 없기 때문에, 이게 없으면
"받는 중" 을 표시할 방법이 없어서 추가했습니다. 실물 오린카도 같은 값을
쓰기로 하면 관제는 시뮬·실물을 구별 없이 다룰 수 있습니다.

> **모르는 `state` 값이 오면 무시하거나 원문 그대로 표시**해 주세요.
> 앞으로 값이 늘어날 수 있습니다.

### 끊김 판정

`ts` 가 **3초 이상** 갱신되지 않으면 그 차량을 `LOST` 로 간주하는 것을 권합니다.
`pose` 를 아직 못 구한 차량은 그 주기를 **아예 발행하지 않습니다**
(0,0 이 오는 일은 없습니다).

---

## 4. task (발행) — 목적지 지시

### 4.1 단순 이동

```json
{ "taskId": "T-1042", "x": 16.5, "y": 5.0, "yaw": 0.0 }
```

### 4.2 집기 → 놓기

```json
{
  "taskId": "T-1043",
  "pickup":  { "x": 16.5, "y": 5.0,  "yaw": 0.0,   "forkHeight": 0.0 },
  "dropoff": { "x": 5.0,  "y": 9.3,  "yaw": 3.1416, "forkHeight": 1.325 }
}
```

`forkHeight` 가 있으면 그 지점 도착 후 포크를 그 높이로 맞춥니다.

정지(`HOLD`/`ESTOP`) 상태의 차량에 보낸 task 는 **무시**되고 로그만 남습니다.
먼저 `RESUME` 를 보내야 합니다.

---

## 5. control (발행) — 정지 / 재개

```json
{ "command": "ESTOP" }
```

| command | 동작 |
|---|---|
| `ESTOP` | 비상정지. 목표 취소 + 속도 0 을 20 Hz 로 지속 발행해 붙잡음 |
| `HOLD` | 같은 동작, 이벤트 등급만 WARN |
| `RESUME` | 정지 해제 |
| `CANCEL_TASK` | 현재 목표만 취소 (정지 아님) |

전체 정지는 `fast/v1/control/all` 에 같은 페이로드를 보냅니다.

정지 중에는 `state` 가 `ESTOPPED` / `HOLDING` 으로 바뀌어 telemetry 로
되돌아오므로, 관제 화면은 이 필드만 보면 됩니다.

---

## 6. cargo (발행) — 화물 지시

```json
{ "height": 0.15, "cargoId": "C-0007" }        // 바이에서 화물 받기 (실물 m)
{ "action": "align_bay" }                       // 바이 정면 정렬
{ "action": "place_rack", "rack": "A1" }        // 랙에 적재
{ "action": "drop" }                            // 지금 자리에 내려놓기
```

`height` 만 **실물 미터**입니다 (카메라 측정값을 그대로 전달하기 때문).
나머지 좌표는 모두 시뮬 좌표계입니다.

### 랙 슬롯

`A1`~`A12` (왼쪽 벽), `B1`~`B12` (가운데). 각 슬롯의 좌표:

| 랙 | 접근점 x | 도킹 x | 적재점 x | y (12칸) |
|---|---|---|---|---|
| A | 5.0 | 2.60 | 0.95 | 9.3 / 10.5 / 11.8 / 13.2 / 14.5 / 15.8 / 17.2 / 18.5 / 19.7 / 21.2 / 22.5 / 23.8 |
| B | 14.5 | 11.95 | 10.20 | 위와 동일 |

선반 높이(포크 목표)는 `1.325`, 진입 방향 yaw 는 `3.1416`(서쪽).

**높이 값 환산** — 모두 시뮬 단위이며 실물은 ÷10 입니다.

| 항목 | 시뮬 (MQTT) | 실물 |
|---|---|---|
| 선반 높이 | 1.325 | 132.5 mm |
| 포크 최대 | 1.5 | 150 mm |
| 파레트 두께 | 0.21 | 21 mm |
| 화물 전체 최대 (파레트+상자) | 1.11 | 111 mm |

**접근점까지만 Nav2 로 가고, 그 뒤 도킹·적재·후진은 차량이 자체 수행**합니다.
백엔드는 접근점 도착을 확인한 뒤 `place_rack` 만 보내면 됩니다.

---

## 7. 백엔드가 구현할 것 — 교통 규칙

현재 교통 규칙은 F팀의 파이썬(`demo_loop2.py`)이 **로컬 ROS 로 직접** 돌리고
있습니다. 이걸 백엔드로 옮기면 시뮬과 실물을 한 곳에서 관제할 수 있습니다.

옮겨야 할 것은 **판단 로직뿐**입니다. 명령 전달 수단(위 토픽들)은 이미 전부
열려 있습니다.

| 옮길 것 | 설명 |
|---|---|
| **호장(arc-length) 투영** | 차량 (x,y) 를 순환로 위 거리 `s` 로 변환. `gap = (s_other − s_me) mod 67.0` 로 앞뒤 판정. **유클리드 거리로는 세로 통로에서 오판**합니다 |
| **일방통행** | 반시계 순환. 모서리 4개: (15.5,4) (15.5,27) (5,27) (5,4), 둘레 67.0 |
| **차간 유지** | 앞차와 `gap < 9.0` 이면 HOLD, `> 6.0` 회복 시 재개 |
| **바이 예약** | 입고 바이(17,5)는 한 대만. 다른 차는 **멈추지 않고 순환로를 계속 돎**(차선에 서면 교착) |
| **진입 간격** | 동시 출발 방지. 한 주기에 한 대씩 합류 허가 |
| **정체 감시** | 20초간 진전 없으면 목표 재전송 |

**구현 설계서가 따로 있습니다** — [backend-control-impl.md](backend-control-impl.md).
데이터 모델·규칙별 Java 의사코드·검증 절차가 들어 있습니다.

알고리즘 배경과 상태 전이는 [traffic-rules-spec.md](traffic-rules-spec.md)
(13장, 조건표 포함)에 있습니다. 참조 구현은
`nav2/scripts/demo_loop2.py` 와 `nav2/scripts/track.py` 입니다.

### 권하는 순서

1. 먼저 **telemetry 를 받아 관제 화면에 차량을 그리는 것**까지
2. 그다음 **정지/재개** (가장 단순하고 효과가 눈에 보임)
3. 그다음 **목적지 지시**
4. 마지막에 **교통 규칙 전체 이식**

3번까지는 F팀 데모와 병행해도 충돌하지 않습니다. 4번은 F팀 데모를 끄고
전환해야 합니다 (둘 다 목표를 보내면 서로 밀어냅니다).

---

## 8. 시험 방법

브로커에 붙어 직접 확인할 수 있습니다.

```bash
# 지금 흐르는 것 전부 보기
mosquitto_sub -h i15a304.p.ssafy.io -p 8883 -u <아이디> -P <비번> \
  --cafile fast-mqtt-ca.crt --insecure -t '#' -v -W 10

# 차량 하나 세우기
mosquitto_pub -h i15a304.p.ssafy.io -p 8883 -u <아이디> -P <비번> \
  --cafile fast-mqtt-ca.crt --insecure \
  -t 'fast/v1/vehicle/sim02/control' -m '{"command":"ESTOP"}'

# 목적지 주기
mosquitto_pub ... -t 'fast/v1/vehicle/sim02/task' \
  -m '{"taskId":"T-1","x":16.5,"y":5.0,"yaw":0.0}'
```

F팀 시뮬이 켜져 있어야 반응합니다. 필요한 시각을 알려주면 맞춰 띄우겠습니다.

`--insecure` 는 hostname 검증만 끄는 옵션이라 `--cafile` 이 반드시 함께
있어야 합니다 (없으면 `A TLS error occurred`).

---

## 9. 아직 정하지 못한 것

| 항목 | 내용 |
|---|---|
| `arrived` 토픽 접두사 | 혼자 `forklift/` 를 씁니다. `fast/v1/vehicle/{id}/arrived` 로 통일할까요? |
| 인증서 | CN 이 IP 라 hostname 검증을 꺼야 합니다. SAN 에 도메인을 넣어 재발급 가능한지 |
| 화물 정보 | `cargo.w/d/h` 외에 무게·품목코드 등이 필요한지 |
| `battery` | 시뮬은 항상 100 입니다. 실물은 C팀이 채울 예정 |

---

문의는 F(디지털 트윈) 에게 주세요. 위 토픽으로 직접 쏴 보면서 확인하는 게
가장 빠릅니다.

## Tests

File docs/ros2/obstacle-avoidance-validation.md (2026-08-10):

# S15P11A304-109 장애물 감지 통합 검증

## 센서 역할

| 센서 | 장착 | 검증 역할 |
|---|---|---|
| EAI YDLIDAR | 차량 상부 | 좌·우 우회 통로와 스캔 높이의 구조물 |
| VL53L8CX 좌 | 포크 방향 정면 좌측 | 좌측 포크 전방의 낮은 사각지대 |
| VL53L8CX 우 | 포크 방향 정면 우측 | 우측 포크 전방의 낮은 사각지대 |
| 카메라 | 차량 정면 | 사람·구조물·타 차량 종류 분류 |

두 ToF는 좌우 측면 감지기가 아니라 모두 정면 감지기다. TF의 yaw는 기본 0이며,
실제 장착 각도를 틀 경우 static TF yaw도 동일하게 수정한다.

## 시험 시나리오

### 낮은 구조물

상부 LiDAR 스캔 높이보다 낮은 상자를 좌측 포크 전방 0.7m에 둔다.

- 좌 ToF가 1.0m 이내를 보고한다.
- 우측 LiDAR 통로가 0.55m 이상 비었으면 `AVOID_RIGHT`와 감속이 발생한다.
- 우측 통로도 막혀 있으면 조향하지 않고 감속하며, **0.25m**에서 정지한다.
- local VoxelLayer에 낮은 상자가 marking되어 Nav2가 재경로를 계산한다.

우측 포크에도 반대 방향으로 같은 시험을 수행한다.

### 높은 구조물

LiDAR 스캔 평면과 교차하는 구조물을 정면 및 좌우에 둔다.

- 정면 **0.25m** 이내에서는 ToF 측정과 관계없이 정지한다.

> **정지거리는 0.45 m 에서 0.25 m 로 내려왔다** (2026-08-07). 현장 충돌 방지 조치와
> 명시적 승인 하에 좁혔다. `base_link` 기준이므로 footprint 전면(x=0.190 m) 대비
> 실제 차체 여유는 **0.06 m** 다.
>
> 근거: 0.45 m 는 폭 2 m 경기장에서 벽을 상시 장애물로 잡아 주행 자체가 불가능했다
> (`test_field_wall_at_43cm_avoids_left_instead_of_stopping` 가 그 회귀를 고정한다).
>
> 값의 authority 는 `config/obstacle_avoidance.yaml` 의 `stop_distance_m` 다.
- 회피 후보 방향이 LiDAR에서 0.55m 미만이면 해당 방향으로 조향하지 않는다.

### 사람·타 차량

카메라가 confidence 0.60 이상의 `person`, `forklift`, `vehicle`, `car` 또는
`truck`을 발행하게 한다.

- 1.5m 이내이거나 거리가 불명확하면 `/cmd_vel_safe`가 0이 된다.
- 동적 장애물은 빈 공간이 보여도 능동 우회하지 않는다.

현재 `pallet/hole` 모델로 이 시나리오를 통과 처리하면 안 된다. 사람·차량 클래스가
포함된 모델의 실제 카메라 입력으로 별도 검증해야 한다.

### 센서 단절

주행 중 `/scan`, 좌 ToF, 우 ToF를 각각 중단한다.

- 0.5초 이내 `SENSOR_TIMEOUT`이 발생한다.
- 선속도와 각속도가 모두 0이 된다.
- 센서 데이터와 TF가 복구된 뒤에만 명령이 다시 통과한다.

## 기록 항목

- 실제 장애물 높이와 거리
- LiDAR 좌·중앙·우 거리
- 정면 좌/우 ToF 거리
- 판단 action과 `/cmd_vel_safe`
- 감지부터 정지 명령까지 걸린 시간
- Nav2 costmap 및 재계획 경로 캡처
- 사람·구조물·타 차량 각 10회 성공률

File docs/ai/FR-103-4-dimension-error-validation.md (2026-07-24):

# FR-103-4 치수 측정 오차 검증

## 1. 목적

카메라로 검출한 화물의 전체 바운딩 박스와 TF-Nova LiDAR 거리값을 결합해 산출한
높이·너비를 실제 치수와 비교한다. 이번 측정은 측정 로직의 예비 성능을 확인하기 위한
단일 표본 검증이며, 최종 인수 결과는 반복 측정 후 별도로 확정한다.

깊이(앞뒤 길이)는 측정 대상에서 제외한다.

## 2. 측정 방식

- 카메라: Logitech BRIO 100, 1920×1080
- 카메라 초점거리: `fx = 2025.17px`, `fy = 2039.07px`
- 거리 센서: TF-Nova LiDAR
- 화물 영역: 검출된 상자들을 모두 감싸는 전체 바운딩 박스
- 실제 치수 계산:

```text
높이(cm) = bbox 픽셀 높이(px) × LiDAR 거리(cm) / fy(px)
너비(cm) = bbox 픽셀 너비(px) × LiDAR 거리(cm) / fx(px)
```

## 3. 예비 측정 결과

실제 크기가 `26.5 × 15.5cm`인 상자를 측정한 결과 `26.8 × 15.3cm`로 산출됐다.

| 항목 | 실제값 | 측정값 | 부호 오차 | 절대 오차 | 상대 오차 | 정확도 |
|---|---:|---:|---:|---:|---:|---:|
| 너비 | 26.5cm | 26.8cm | +0.3cm | 3mm | 1.13% | 98.87% |
| 높이 | 15.5cm | 15.3cm | -0.2cm | 2mm | 1.29% | 98.71% |

계산식은 다음과 같다.

```text
절대 오차 = |측정값 - 실제값|
상대 오차(%) = 절대 오차 / 실제값 × 100
정확도(%) = 100 - 상대 오차
```

종합 결과:

- 평균 절대 오차: `2.5mm`
- 최악 절대 오차: `3mm`
- 평균 상대 오차(MAPE): `1.21%`
- 평균 정확도: `98.79%`

## 4. KPI 예비 판정

프로젝트 치수 측정 KPI는 미니어처 기준 평균 오차 `2mm 이하`, 최악 오차 `4mm 이하`다.
이번 상자를 미니어처 실물 대상으로 직접 평가하면 다음과 같다.

| 기준 | 결과 | 예비 판정 |
|---|---:|---|
| 평균 오차 ≤ 2mm | 2.5mm | 미달 |
| 최악 오차 ≤ 4mm | 3mm | 통과 |

단일 표본 1회 측정이므로 위 결과만으로 최종 KPI 달성 여부를 확정하지 않는다.

## 5. 확인된 오차 원인

촬영 당시 카메라가 상자 정면과 정확히 평행하지 않았다. 현재 검출 모델의 일반 bbox는
회전된 상자도 영상의 가로·세로축에 평행한 직사각형으로 감싸므로, 카메라 또는 상자가
기울어지면 높이 성분 일부가 bbox 너비에 포함되어 너비가 실제보다 크게 산출될 수 있다.

이번 결과에서도 너비는 `+3mm`, 높이는 `-2mm`의 오차를 보였다. 따라서 너비 과대 측정은
카메라 정렬 상태와 축 정렬 bbox의 영향을 받은 것으로 추정한다.

## 6. 결론

카메라 bbox와 TF-Nova LiDAR를 결합한 단일 상자 예비 측정에서 평균 `98.79%`의 치수
정확도와 최악 `3mm`의 절대 오차를 확인했다. 최악 오차 기준은 만족했지만 평균 오차는
목표보다 `0.5mm` 컸다. 카메라 정렬을 보정한 반복 측정으로 최종 성능을 판단한다.

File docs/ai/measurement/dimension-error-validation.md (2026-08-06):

# 치수 측정 오차 검증

> ## ✅ 이 문서는 **예비 판정**이고, 최종 결과는 따로 나왔다
>
> 여기 적힌 **평균 2.5mm(미달) / 최악 3mm** 는 **단일 표본 1회** 측정값이다(문서
> 스스로도 그렇게 적고 있다). 그 뒤 반복 측정으로 **KPI 를 통과했다**:
>
> | | 이 문서(예비) | 최종(2026-07-28, 미니어처 54/54) |
> |---|---|---|
> | 평균 절대 오차 | 2.5mm | **0.66mm** |
> | 최악 절대 오차 | 3mm | **2.10mm** |
> | 판정 | 평균 미달 | **통과** |
>
> ⚠️ **KPI 기준도 이 문서만 다르게 적고 있다.** 여기 §4는 "평균 2mm 이하 · 최악 4mm
> 이하"라고 쓰는데, 레포의 다른 모든 문서와 명세는 **≤4mm** 하나만 KPI 로 쓴다.
> 이 문서를 근거로 "평균 KPI 미달"이라고 읽지 말 것.
>
> 최종 수치·조건은 `docs/ai/station-dim-eval-plan.md` 와 `docs/ai/rig-eval-map.md`.
> **§5(확인된 오차 원인)는 지금도 유효하다** — 가장자리 왜곡·빔 정조준 같은 촬영
> 주의사항이 거기서 나왔다.
>
> *(경위 표시: 2026-08-06, 성능 수치 전수 대조. Jira S15P11A304-178)*

## 1. 목적

카메라로 검출한 화물의 전체 바운딩 박스와 TF-Nova LiDAR 거리값을 결합해 산출한
높이·너비를 실제 치수와 비교한다. 이번 측정은 측정 로직의 예비 성능을 확인하기 위한
단일 표본 검증이며, 최종 인수 결과는 반복 측정 후 별도로 확정한다.

깊이(앞뒤 길이)는 측정 대상에서 제외한다.

## 2. 측정 방식

- 카메라: Logitech BRIO 100, 1920×1080
- 카메라 초점거리: `fx = 2025.17px`, `fy = 2039.07px`
- 거리 센서: TF-Nova LiDAR
- 화물 영역: 검출된 상자들을 모두 감싸는 전체 바운딩 박스
- 실제 치수 계산:

```text
높이(cm) = bbox 픽셀 높이(px) × LiDAR 거리(cm) / fy(px)
너비(cm) = bbox 픽셀 너비(px) × LiDAR 거리(cm) / fx(px)
```

## 3. 예비 측정 결과

실제 크기가 `26.5 × 15.5cm`인 상자를 측정한 결과 `26.8 × 15.3cm`로 산출됐다.

| 항목 | 실제값 | 측정값 | 부호 오차 | 절대 오차 | 상대 오차 | 정확도 |
|---|---:|---:|---:|---:|---:|---:|
| 너비 | 26.5cm | 26.8cm | +0.3cm | 3mm | 1.13% | 98.87% |
| 높이 | 15.5cm | 15.3cm | -0.2cm | 2mm | 1.29% | 98.71% |

계산식은 다음과 같다.

```text
절대 오차 = |측정값 - 실제값|
상대 오차(%) = 절대 오차 / 실제값 × 100
정확도(%) = 100 - 상대 오차
```

종합 결과:

- 평균 절대 오차: `2.5mm`
- 최악 절대 오차: `3mm`
- 평균 상대 오차(MAPE): `1.21%`
- 평균 정확도: `98.79%`

## 4. KPI 예비 판정

프로젝트 치수 측정 KPI는 미니어처 기준 평균 오차 `2mm 이하`, 최악 오차 `4mm 이하`다.
이번 상자를 미니어처 실물 대상으로 직접 평가하면 다음과 같다.

| 기준 | 결과 | 예비 판정 |
|---|---:|---|
| 평균 오차 ≤ 2mm | 2.5mm | 미달 |
| 최악 오차 ≤ 4mm | 3mm | 통과 |

단일 표본 1회 측정이므로 위 결과만으로 최종 KPI 달성 여부를 확정하지 않는다.

## 5. 확인된 오차 원인

촬영 당시 카메라가 상자 정면과 정확히 평행하지 않았다. 현재 검출 모델의 일반 bbox는
회전된 상자도 영상의 가로·세로축에 평행한 직사각형으로 감싸므로, 카메라 또는 상자가
기울어지면 높이 성분 일부가 bbox 너비에 포함되어 너비가 실제보다 크게 산출될 수 있다.

이번 결과에서도 너비는 `+3mm`, 높이는 `-2mm`의 오차를 보였다. 따라서 너비 과대 측정은
카메라 정렬 상태와 축 정렬 bbox의 영향을 받은 것으로 추정한다.

## 6. 결론

카메라 bbox와 TF-Nova LiDAR를 결합한 단일 상자 예비 측정에서 평균 `98.79%`의 치수
정확도와 최악 `3mm`의 절대 오차를 확인했다. 최악 오차 기준은 만족했지만 평균 오차는
목표보다 `0.5mm` 컸다. 카메라 정렬을 보정한 반복 측정으로 최종 성능을 판단한다.

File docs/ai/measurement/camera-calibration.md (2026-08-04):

# 카메라 캘리브레이션

카메라가 둘이고 **쓰는 축이 다르다.** 헷갈리지 말 것.

| | 스테이션 (BRIO) | 온보드 (Jetson USB) |
|---|---|---|
| 용도 | 화물 치수·적재 높이 | 포크 정렬 요각·거리 |
| 해상도 | 1920×1080 | 1280×720 |
| **쓰는 값** | **`fy` = 2039.07** (세로) | **`fx` = 1277.65** (가로) |

축이 다른 이유: 스테이션은 **적재 높이**(세로)를 재고, 온보드는 **가로로 놓인 구멍 두 개**의
간격을 본다(`tanθ = 2f/span · yaw_signal`의 span이 가로 픽셀 거리).

---

# 1. 스테이션 (Logitech BRIO 100)

## 사용 장비

- 카메라: Logitech BRIO 100
- 촬영 해상도: 1920 × 1080
- 체커보드 내부 코너: 9 × 6
- 체커보드 한 칸 크기: 24 mm

## 카메라 내부 파라미터

| 항목 | 값 | 의미 |
|---|---:|---|
| `fx` | 2025.17 px | 가로 방향 초점거리 |
| `fy` | 2039.07 px | 세로 방향 초점거리 |
| `cx` | 969.79 px | 광학 중심의 가로 좌표 |
| `cy` | 459.43 px | 광학 중심의 세로 좌표 |

적재 높이 계산에는 세로 방향 초점거리 `fy = 2039.07 px`를 사용한다.

## 검증 결과

60 cm 거리에서 실제 크기가 22 × 17.5 cm인 마우스패드를 측정한 결과,
높이 방향 기준 약 98.24%의 정확도를 확인했다.

위 결과는 해당 거리와 촬영 조건에서 수행한 단일 기준물 검증 결과이다.
카메라 해상도, 화각 또는 디지털 줌 설정이 변경되면 다시 캘리브레이션해야 한다.

---

# 2. 온보드 (Jetson USB 카메라) — 2026-07-31

포크 정렬(S15P11A304-152)의 요각·거리를 **절대 단위**로 내기 위한 값. 이것이 없으면
`AlignError.yaw_deg`·`distance_mm`이 `None`이고 DoD의 "요각 ±5°"를 판정할 수 없다.

## 사용 장비

- 카메라: USB(UVC) 모듈, Jetson `/dev/video0`, **1280 × 720**
- 체커보드: **스테이션과 동일** — 9 × 6 내부 코너, 한 칸 24 mm
- 도구: `ai/scripts/calibrate_camera.py` (촬영 `shoot` / 풀이 `solve`)
- 촬영 시 `--rotate180` (카메라를 뒤집어 장착)

## 카메라 내부 파라미터

| 항목 | 값 | 비고 |
|---|---:|---|
| **`fx`** | **1277.65 px** | ← **포크 정렬에 쓰는 값** |
| `fy` | 1284.13 px | fx와 0.5% 차 (정사각 픽셀, 정상) |
| `cx` | 630.65 px | 화면 중앙 640에서 9px |
| `cy` | 306.82 px | |
| 재투영 RMS | **0.312 px** | 합격선 0.5 통과 |
| 사용 장수 | 18 / 20 | 흔들린 2장 자동 제외 |

왜곡: `[-0.237665, 1.114489, -0.000914, -0.003143, -1.492558]`

원본 `calibration.json`은 젯슨 `~/calib/shots/`.

## 신뢰 근거 (독립적인 셋)

1. **RMS 0.312 px** — 첫 시도 3.649에서 열 배 개선
2. **`cx`가 화면 중앙에 근접**(630.7 vs 640). 해가 발산하면 여기가 먼저 튄다 — 실패한
   시도에서는 92.98(왼쪽 끝)이 나왔다
3. **모델을 5가지로 바꿔도 `fx` 변동 0.1%**(1304.0~1305.3). 실패한 시도에서는
   1442~1612로 흔들렸다
4. 화각 환산 대각 **59.9°** — USB 카메라 모듈의 전형값

## ⚠️ 실패에서 배운 것 — 블러가 자세 다양성보다 먼저다

첫 두 번의 촬영이 실패했고 **원인은 자세가 아니라 모션 블러**였다.

움직이는 중에 저장된 장이 20장 중 14장이었고, 선명도와 재투영 오차가 정확히 반대로
갔다 — 선명도 70~208인 장이 5~6.5px, 455~557인 장이 0.44~0.86px. 전체 RMS 3.65px.

**자유 파라미터를 줄여도(광학중심 고정 등) RMS가 안 내려갔다.** 그것이 "모델 문제가
아니라 데이터 문제"라는 신호였다. 코너는 서브픽셀로 잡히므로 몇 px만 흘러도 그대로
오차가 된다.

→ `calibrate_camera.py`는 이제 **직전 프레임 대비 코너 이동이 1px 미만일 때만 저장**한다.
촬영 안내도 "자세를 바꾸세요"에서 **"자세 잡고 멈추세요"** 로 바꿨다.

## ⚠️ 카메라를 옮기면 무엇이 바뀌나

| | 카메라 재장착 시 |
|---|---|
| `fx`·`fy`·`cx`·`cy`·왜곡 | **그대로** — 렌즈·센서의 성질이다 |
| `fork_center_x` | **다시 재야 한다** — 포크 중심선의 화면 x |
| `ALIGN_ENTER_MM`·`INSERT_ENTER_MM` | **다시 재야 한다** |

거리 임계가 장착에 종속되는 이유: "구멍이 화면에서 사라지는 거리"는 카메라의 **높이와
내려다보는 각**에 달렸다. 각 θ가 커지면 개구가 `9.5 × cosθ`로 납작해져(라벨 가이드 §5)
더 먼 거리에서 이미 안 보인다.

**해상도를 바꿔도 다시 해야 한다** — 초점거리는 픽셀 단위다. 다만 가로 해상도가 같으면
(1280×720 → 1280×800 등) `fx`는 유지된다.

## 미완 — 거리 임계 실측 (파츠 대기 중)

`fork_servo`의 `ALIGN_ENTER_MM`(**650**) · `INSERT_ENTER_MM`(180)은 **아직 추정값**이다.
카메라 고정 파츠를 3D 프린트한 뒤 실측해야 한다.

> 2026-08-03 예정이었으나 **출력이 안 나와 밀렸다.** 파츠 없이 손으로 각도를 잡으면
> 매번 달라져 조정해봐야 파츠 붙이면 다시 해야 한다.

⚠️ **`ALIGN_ENTER_MM` 은 임의로 고치면 안 된다 — 만족해야 할 산수가 있다.** 최소
회전반경 53.7cm 기준 좌우 오프셋 10cm 를 지우는 데 전진 45cm 가 필요하고, 그 거리는
ALIGN 구간에서만 벌 수 있으므로:

    ALIGN_ENTER_MM ≥ INSERT_ENTER_MM + 450

종전 값 350 은 이 조건을 깨고 있었다(ALIGN 구간이 170mm 뿐) — **10cm 틀어져 있으면
기하학적으로 못 고치고 반드시 ABORT** 한다. 2026-08-03 에 650 으로 고쳤다(S15P11A304-191).
실측값을 넣을 때도 이 부등식을 확인할 것.

⚠️ **px 임계는 손으로 고르지 않는다.** `ALIGN_ENTER_PX`·`INSERT_ENTER_PX` 는 위 mm
값에서 유도된다(`span_px = fx × 48.5 / distance_mm`). 따로 고르면 **같은 이름인데 다른
거리**가 되어, `--focal-px` 를 주느냐 마느냐로 동작이 갈린다(실제로 그랬다).

측정 도구는 준비돼 있다 — `ai/scripts/pallet_ruler.py`:

```
PYTHONPATH=src python3 scripts/pallet_ruler.py \
    --engine ~/trt_test/onboard_s640_ep116_fp16.engine \
    --plugin ~/mmdeploy/build_trt/lib/libmmdeploy_tensorrt_ops.so \
    --camera 0 --rotate180 --focal-px 1277.7
```

Ctrl-C 시 요약이 나온다:
- **구멍이 보인 가장 가까운 거리** → `INSERT_ENTER_MM`의 상한
- **파렛트가 잡힌 가장 먼 거리** → `ALIGN_ENTER_MM`의 상한

같은 자리에서 `fork_center_x`(포크 중심선의 화면 x)도 같이 잰다.

⚠️ **반드시 차에 장착한 상태로** 재야 한다. 손으로 들면 높이·각도가 제멋대로라 그 값을
차에 쓸 수 없다. 다만 **주행은 필요 없다** — 세워두고 파렛트만 밀었다 당기면 된다.

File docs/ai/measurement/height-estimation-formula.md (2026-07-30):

# 높이 산출 공식

RTMDet으로 검출한 적재 상자 영역에서 최상단과 최하단의
픽셀 좌표를 이용해 픽셀 높이를 계산한다.

## 계산식

```text
픽셀 높이(px) = 최하단 y 좌표 - 최상단 y 좌표

적재 높이(cm) =
    픽셀 높이(px) × LiDAR 거리(cm) / 카메라 세로 초점거리(px)
```

현재 Logitech BRIO 100의 세로 초점거리는 다음 값을 사용한다.

```text
fy = 2039.07 px
```

예를 들어 픽셀 높이가 600 px이고 LiDAR 거리가 100 cm이면 다음과 같다.

```text
적재 높이 = 600 × 100 / 2039.07
          ≈ 29.43 cm
```

깊이를 측정하지 않으므로 실제 용적은 계산하지 않고
팔레트 위 적재물의 높이만 산출한다.

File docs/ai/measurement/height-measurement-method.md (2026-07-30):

# 높이 측정 방식 정의

RTMDet으로 팔레트 위 적재 상자의 영역을 검출한다.

검출된 상자 바운딩박스 중 최상단과 최하단 좌표를 이용해
사진상의 적재 높이를 픽셀 단위로 계산한다.

TF-NOVA LiDAR로 적재물 전면까지의 거리를 측정한다.
거리값을 사용하면 상자가 팔레트의 앞쪽이나 뒤쪽에 놓였을 때
발생하는 픽셀 크기 차이를 보정할 수 있다.

카메라의 세로 방향 초점거리 `fy`와 TF-NOVA 거리값을 이용하여
팔레트 상판부터 적재물 최상단까지의 실제 높이를 산출한다.

깊이는 측정하지 않으므로 실제 용적을 계산하지 않고,
용적 근사를 위한 적재 높이만 산출한다.

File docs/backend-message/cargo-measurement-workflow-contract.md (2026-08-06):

# 화물 측정 연동 계약

이 문서는 백엔드 밖의 ROS2·AI·Isaac Sim 담당자가 구현해야 할 최소 계약을 정리한다. 백엔드는 DB와 아래 MQTT/REST 경계까지만 책임진다.

## 전체 순서

```text
화물 등록과 운반 작업 원자적 생성 및 차량 배정
→ taskId가 포함된 측정 위치 MOVE 명령 발행
→ ROS2가 MOVE 결과 SUCCESS 반환
→ 백엔드가 작업을 MEASURING으로 커밋하고 측정 설비가 비기를 기다림
→ 활성 세션이 없을 때
→ 백엔드가 cargoId로 fast/station/measure_request 발행
→ AI 측정 프로그램이 기존 REST API로 측정 세션 생성
→ 백엔드가 세션과 대기 중인 운반 작업 연결
→ AI 측정 프로그램이 1회 촬영·추론
→ AI 측정 프로그램이 최종 결과를 REST로 등록
→ 백엔드가 적재 위치를 선택·예약하고 작업을 PICKING_UP으로 전환
→ AI의 기존 세션 종료 DELETE는 이미 자동 해제된 세션으로 안전하게 처리
```

작업 상태는 `ASSIGNED → MOVING_TO_PICKUP → MEASURING → PICKING_UP` 순서로 진행한다.
`MEASURING`에서 `measurement_requested_at`이 null이면 측정 위치 도착 후 설비 해제를 기다리는 상태다.
측정 결과가 안전 조건을 만족하지 않거나 빈 적재 위치가 없으면 `FAILED`로 종료한다.

## ROS2 담당 계약

ROS2는 기존 `forklift/{vehicleId}/command`의 MOVE 명령을 실행하고 결과를 `forklift/{vehicleId}/command-result`로 반환한다.

- 받은 `commandId`, `vehicleId`, `targetSystem`, `commandCategory`, `command`를 결과에 그대로 사용한다.
- Nav2 목표 도착이 성공했을 때만 `result=SUCCESS`를 보낸다.
- 취소·실패·거부는 각각 `CANCELLED`, `FAILED`, `REJECTED`로 보낸다.
- 좌표계는 `map`, 좌표는 m, `heading`은 degree를 사용한다.
- ROS2가 측정 요청 토픽을 직접 발행하거나 `cargoId`를 관리하지 않는다.

> ✅ **연결 완료**(2026-08-03, S15P11A304-192·193). `fast_mqtt_bridge/nav2_adapter.py` ·
> `nav2_goal_sender.py` 가 MOVE 를 `NavigateToPose` 액션으로 실행하고, 회전 없이 도는
> 행동트리(`forklift_teleop/behavior_trees/navigate_to_pose_no_spin.xml`)를 물렸다.
> ⚠️ **배선까지만 검증됐고 실주행은 미검증**이다.
>
> ⚠️ **`/cmd_vel` 인계 규칙이 없다**(S15P11A304-**199**). Nav2 와 포크 정렬 루프가 같은
> 토픽을 동시에 잡을 수 있다 — 지금은 포크 정렬 전에 **사람이 Nav2 를 내린다.**

MOVE 목표 종료 결과는 아래 형식으로 반환한다.

```json
{
  "commandId": "uuid",
  "vehicleId": "FORKLIFT-01",
  "targetSystem": "ROS2",
  "commandCategory": "MOVE",
  "command": "MOVE",
  "result": "SUCCESS",
  "message": "goal reached",
  "completedAt": "2026-08-02T10:00:00+09:00"
}
```

## AI 측정 프로그램 담당 계약

### 측정 요청 수신

- 토픽: `fast/station/measure_request`
- 방향: 백엔드 → AI 측정 프로그램
- QoS: 1
- retained: false

```json
{
  "cargoId": 1
}
```

- 요청 한 건당 한 번 측정하고 최종 결과 한 건만 전송한다.
- `cargoId`는 백엔드가 `POST /api/cargos`에서 자동 생성한 64비트 정수다.
- AI는 기존 `POST /api/stations/sessions?cargoId=...` API로 세션을 생성한다.
- 운영 환경에서는 백엔드 MQTT 요청을 받은 경우에만 세션 생성 API를 호출한다. 수동 테스트 호출은
  다음 측정 요청보다 먼저 설비를 점유할 수 있으므로 운영 흐름과 분리한다.
- 백엔드는 생성된 세션을 같은 `cargoId`의 측정 대기 작업과 연결한다.
- 이미지 파일은 저장하지 않는다. 실시간 영상 표시가 필요하면 측정 결과 계약과 별도 스트림으로 구현한다.

정상 측정 결과가 저장되고 작업이 `PICKING_UP`으로 전환되면, 측정 트랜잭션 커밋 후
`CARGO_INTAKE_NEXT_DELAY_MS`(기본 5000ms)가 지난 시점에 다음 화물과 `PENDING` 운반 작업을
자동 생성한다. 부적합 측정, 적재 위치 추천 실패, 세션 TTL 만료에서는 자동 생성하지 않는다.
자동 입하는 `CARGO_INTAKE_AUTO_CREATE_ENABLED`(기본 `true`)로 끌 수 있다.

현재 AI의 `trigger.py`, `serve.py`, `rest_client.py` 세션 생성 흐름을 그대로 사용한다.

### TTL 실패 처리

- 백엔드가 측정 위치 MOVE 명령을 발행한 뒤 300초 안에 MOVE 결과를 받지 못하면 작업을
  `FAILED`로 종료한다. 기준 시각은 `transport_task.started_at`이다.
- MOVE 성공 시 설비 상태를 즉시 확인하고, 이전 세션이 남아 있으면 MQTT를 발행하지 않고 1초마다
  다시 확인한다.
  이 대기까지 `started_at` 기준 300초를 넘으면 작업을 `FAILED`로 종료한다.
- 요청 발행 조건에도 같은 300초 경계를 적용하므로 정리 스케줄러보다 발행 스케줄러가 먼저 실행돼도
  만료 작업은 MQTT로 내보내지 않는다.
- 백엔드가 측정 요청을 발행하면 `transport_task.measurement_requested_at`을 기록한다.
- 설정된 TTL 안에 AI가 세션을 열지 않으면 작업을 `FAILED`로 종료한다.
- AI가 세션을 열었지만 TTL 안에 최종 결과를 저장하지 못해도 세션을 자동 해제하고 작업을 `FAILED`로 종료한다.
- 실패한 작업은 재측정하지 않으며 다음 대기 작업이 측정 차선을 사용할 수 있다.
- 설비 점유 중에는 아직 측정 요청을 발행하지 않은 것이므로 재측정으로 보지 않는다.
- 측정 요청 발행 주기는 `STATION_MEASUREMENT_REQUEST_DISPATCH_INTERVAL_MS`(기본 1초)다.
- 정리 주기는 `STATION_SESSION_CLEANUP_INTERVAL_MS`(기본 5초)다.
- MOVE 결과와 설비 해제 대기 상한은 `STATION_MOVE_TTL_SECONDS`(기본 300초), 측정 요청·활성 세션
  TTL은 `STATION_SESSION_TTL_SECONDS`(기본 60초)로 설정한다.

### 최종 결과 등록

AI 측정 프로그램은 세션 생성 API에서 받은 `sessionId`를 그대로 사용해 `POST /api/stations/measurements`로 결과를 등록한다.

```json
{
  "sessionId": "uuid",
  "measurementId": "station-20260802-0001",
  "status": "ok",
  "cargoHeight": 0.723,
  "tippingLevel": "safe",
  "overhangRatio": 0.04
}
```

- `cargoHeight`: 팔레트를 제외한 화물 높이(m)
- `status`: `ok`, `dimensions_only`, `no_detection`, `unreliable`
- `ok`일 때 `tippingLevel`과 `overhangRatio`가 필수다.
- `sessionId`가 현재 활성 세션과 다르면 백엔드는 이전 화물의 늦은 결과로 판단해 거부한다.
- AI의 기존 `DELETE /api/stations/sessions/{sessionId}` 호출은 유지한다. 결과 저장으로 이미 자동 해제된
  경우 백엔드는 `STATION_SESSION_NOT_ACTIVE`를 반환하고 AI는 이를 정상 종료로 처리한다.

## Isaac Sim 담당 계약

- 측정 시작 여부와 작업 상태를 판단하지 않는다.
- 기존 WebRTC 화면 송출 구조를 유지한다.
- 기존 `twin_bridge.py` 위치 형식(`forkliftId`, `x`, `y`, `direction`, `timestamp`)을 유지한다.
- 백엔드가 Isaac 위치를 ROS2 표준 위치 형식으로 변환해 DB와 관제 WebSocket에 반영한다.
- 실물 미니어처 AMCL `map` 좌표가 기준이며, 현실 스케일 모델의 배율 변환은 Isaac Sim 내부에서 처리한다.

현재 WebRTC 및 시각화 코드는 유지한다. Isaac Sim은 이동 완료 `command-result`를 발행하지 않고,
ROS2가 Nav2 실행 결과를 백엔드에 반환한다. Isaac Sim이 `fast/station/measure_request`를 직접 발행하던
구조가 있다면 제거하고 ROS2의 MOVE 결과만 사용한다.

## Embedded 담당 계약

이 측정 흐름 때문에 변경할 사항은 없다. 기존 주행·포크 UART 및 리미트 스위치 제어를 유지한다.

## 백엔드가 보장하는 항목

- 한 번에 하나의 작업만 측정 위치로 이동하거나 측정할 수 있다.
- `vehicle_command.task_id`로 MOVE 결과와 운반 작업을 연결한다.
- MOVE 성공 후 활성 세션이 남아 있으면 요청을 유실하지 않고 설비 해제까지 대기한다.
- AI가 세션을 생성하면 같은 `cargoId`의 측정 대기 작업에 연결한다.
- `transport_task.measurement_session_id`로 측정 결과의 대상 작업을 확정한다.
- 측정 요청 실패, MOVE 실패, 부적합 측정 결과는 작업을 `FAILED`로 종료한다.
- MOVE 결과, 측정 요청 또는 활성 측정 세션이 각각의 TTL을 넘으면 작업을 `FAILED`로 종료하고
  차선을 자동 해제한다.
- AI 측정 결과는 MQTT가 아니라 REST 한 경로로만 받는다.

## 배포 유의 사항

변경 전 버전이 만든 `MOVING_TO_PICKUP + measurement_requested_at 존재` 작업은 새 상태 규칙과 호환되지
않는다. MVP DB를 초기화하지 않고 배포한다면 진행 중인 측정 작업이 없는 것을 확인한 뒤 교체한다.

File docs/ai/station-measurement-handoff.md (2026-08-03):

# 스테이션 측정 결과 핸드오프 (FR-101/103/104 → FR-201/202)

스테이션이 실물 화물을 재서 내는 **측정 결과 JSON** 규격이다. 적재 위치 산출
(FR-202, S15P11A304-34)이 이 값을 입력으로 쓴다.

- 생산자: `ai/src/station/serve.py` (모델·거리계 배선) → `station/pipeline.build_payload`
- 소비자: 적재 공간 인식·최적 위치 산출 (전지웅) / 백엔드 저장·관제 (김재원)
- 규격 버전: `schema_version: "1.1"`

## 변경 이력

| 버전 | 날짜 | 변경 |
|---|---|---|
| 1.0 | 2026-07-24 | 최초 규격 (dimensions · box_measurements · load_balance) |
| **1.1** | **2026-07-29** | **`tipping` 블록 추가** (전복 위험, FR-103) |

> ⚠️ **필드를 추가하면 버전을 반드시 올린다.**
> `tipping`은 실제로는 2026-07-28(MR !75)에 payload에 들어갔는데 `schema_version`을 1.0에
> 둔 채였다. 호환을 깨는 변경이 아니라 추가라서 넘어갔지만, **소비자에게는 규격이 바뀐 것을
> 알 수단이 없었다.** 그 결과 백엔드는 `tipping`을 모른 채로 두었고, Spring Boot가 모르는
> JSON 필드를 기본으로 무시하는 탓에(`FAIL_ON_UNKNOWN_PROPERTIES=false`) **에러도 로그도 없이
> 조용히 버려졌다.** 발견까지 하루가 걸렸다.

> ## ⚠️ 백엔드 전달은 REST다 — 이 JSON을 그대로 보내지 않는다
>
> 아래 JSON은 **비전 파이프라인의 출력 원본**이다. 백엔드 저장은 MQTT가 아니라 REST이며
> (`fast/station/+/measurement` 토픽은 **제거됐다**), 계약이 원본보다 훨씬 좁다.
>
> | 백엔드 REST 필드 | 이 문서의 원본 필드 | 변환 |
> |---|---|---|
> | `sessionId` | 세션 생성 API 응답의 `sessionId` | AI가 생성한 측정 세션 값을 그대로 전송 |
> | `measurementId` | `measurement_id` | 없음 |
> | `status` | `status` | 없음(`dimensions_only` 포함 4값 지원) |
> | **`cargoHeight`** | **`dimensions.height_cm`** | **cm ÷ 100 = m** — 데스크탑이 변환 |
> | `tippingLevel` | `tipping.level` | 소문자 그대로 보내면 백엔드가 대문자로 저장 |
> | `overhangRatio` | `tipping.overhang` | 없음 |
> | ~~`measuredAt`~~ | ~~`measured_at`~~ | **백엔드 DTO에서 제거됐다**(2026-08-02 리팩터). 보내도 무시된다 — 아래 참조 |
>
> ```
> POST /api/stations/measurements   Content-Type: application/json
> { "sessionId": "...", "measurementId": "...", "status": "ok", "cargoHeight": 0.723,
>   "tippingLevel": "safe", "overhangRatio": 0.04 }
> ```
>
> ⚠️ **`measuredAt`은 더 이상 계약에 없다.** `StationMeasurementCreateRequest`에서
> 제거됐고 저장 시각은 서버가 `createdAt`으로 남긴다. 클라이언트가 아직 보내고 있지만
> Spring 이 `fail-on-unknown-properties` 를 켜지 않아 **조용히 버려진다**(무해). 즉시
> 저장되는 흐름이라 실측에서 두 시각이 사실상 같았다(12:12:00 vs 12:12:00.376).
>
> ⚠️ **위 예시의 `overhangRatio` 를 0.057 에서 0.04 로 고쳤다.** 0.05 **이상**이면
> `placementEligible: false` 가 되어 적재 추천이 나가지 않는다. 정상 흐름 예시에
> 실패하는 값을 쓰고 있었다.
>
> 백엔드 MQTT 측정 요청에는 `cargoId`만 들어온다. AI가
> `POST /api/stations/sessions?cargoId=...`로 세션을 생성한 뒤, 응답으로 받은 **`sessionId`를 반드시 보낸다.**
> 활성 세션과 다르면 백엔드는 늦게 도착한 이전 화물 결과로 판단해 거부한다. `stationId`는 보내지 않는다.
> 나머지 필드(detection/distance/load_balance/box_measurements/miniature/total_height)는
> **백엔드에 저장되지 않는다.** 전체 규격은 `docs/backend-message/communication-protocol.md`
> §Measurement Station v2.0 (REST) 참고.

## 한눈에

```jsonc
{
  "schema_version": "1.1",
  "measurement_id": "station-1-20260729-093509-0001",
  "station_id": "station-1",
  "measured_at": "2026-07-29T09:35:09+09:00",
  "status": "ok",

  "dimensions": {
    "height_cm": 72.3,                  // 화물만 (파렛트 제외)
    "total_height_cm": 84.3,            // ★ 화물 + 파렛트 — 적재 판단은 이 값
    "pallet_height_cm": 12.0,
    "width_cm": 102.2,
    "depth_cm": null,                   // 정면 카메라라 측정 불가 — 항상 null
    "miniature_scale": 10,
    "miniature_height_mm": 72.3,
    "miniature_total_height_mm": 84.3,  // ★ 미니어처 환산 총높이
    "miniature_width_mm": 102.2,
    "tilt_deg": null                    // 적용된 롤 보정각. null이면 보정 안 함
  },

  "tipping": {                          // 전복 위험 (FR-103)
    "assessable": true,
    "level": "safe",                    // safe | warning | danger
    "static_stable": true,
    "support_offset": 0.027,            // 1.0 = 무게중심이 파렛트 끝(전복 한계)
    "margin": 0.973,
    "direction": null,                  // "left" | "right" | null
    "aspect_ratio": 0.71,
    "overhang": 0.0,
    "message": "안정 (무게중심 이탈 3%, 한계까지 97% 여유)"
  },

  "load_balance": {                     // 편하중 (FR-104)
    "eccentric": false,
    "direction": [],                    // ["left"] | ["right"] | []
    "ratio_x": 0.03,
    "ratio_y": null,                    // 정면 뷰라 앞뒤는 판정 안 함 — 항상 null
    "magnitude": 0.03,
    "threshold": 0.3,
    "message": "정상 (치우침 0.03 ≤ 0.3)"
  },

  "detection": { "box_count": 5, "boxes": [...], "pallet": {...} },
  "distance":  { "front_cm": 236.0, "std_cm": 0.0, "frames_used": 100 },
  "box_measurements": [ /* 박스별 치수 — 아래 참고 */ ]
}
```

## 적재 로직이 실제로 쓸 값

| 목적 | 필드 | 단위 |
|---|---|---|
| **적재 높이(백엔드 REST)** | `dimensions.height_cm` ÷ 100 → `cargoHeight` | **m (화물만)** |
| 미니어처 환산 | `dimensions.miniature_total_height_mm` | mm |
| **적재 폭** | `dimensions.width_cm` | cm |
| 안전 판정 | `tipping.level`, `load_balance.eccentric` | — |

> ⚠️ **백엔드 REST로는 `height_cm`(화물만)을 m로 바꿔 보낼 것.** 팔레트 높이를 미리 더하지 않는다.
>
> 랙 간섭 판단에 총높이가 필요한 것은 맞지만, **팔레트 높이를 더하는 주체가 백엔드로 정해졌다** —
> 백엔드가 설정값 `storage.placement.pallet-height-m`(0.12)를 `PlacementService`에서 **정확히 한 번**
> 더한다(`requiredHeight = cargoHeight + 0.12 + clearance`). `total_height_cm`을 `cargoHeight`로 보내면
> **팔레트 높이가 두 번 더해진다.**
>
> `total_height_cm` / `miniature_total_height_mm` 자체는 이 문서의 원본 출력으로 남지만,
> **백엔드 FR-202 계산 입력으로는 쓰지 않는다.**

> ⚠️ **깊이(`depth_cm`)는 항상 null.** 정면 단일 카메라라 앞뒤를 못 잰다(명세 §2.2).
> 적재 단위가 파렛트(T-11 고정 규격 1100×1100mm)이므로 깊이는 규격값을 쓰면 된다.

### 단위 규약
- `*_cm` = **실물** 치수, `miniature_*_mm` = **미니어처**(실물 ÷ 10) 치수
- 미니어처 데모에서 실제로 옮기는 물체는 1/10 축소본이므로, 트윈·배치 계산은
  `miniature_*` 쪽을 쓰는 편이 헷갈리지 않는다. 둘 다 같은 측정에서 나온 값이다.

## status — 값이 언제 채워지나

**키는 status와 무관하게 항상 존재한다.** 값이 없으면 `null`이거나
`{"assessable": false, "reason": ...}`이므로, 키 유무를 분기할 필요가 없다.

| status | 뜻 | dimensions | tipping | load_balance |
|---|---|---|---|---|
| `ok` | 정상 | ✅ | ✅ | ✅ |
| `dimensions_only` | **파렛트 미검출** — 치수만 | ✅ | `assessable:false` | `null` |
| `no_detection` | 박스 없음 | `null` | `assessable:false` | `null` |
| `unreliable` | 거리 측정 실패 | `null` | `assessable:false` | `null` |

→ **`status == "ok"`가 아니면 적재 판단에 쓰지 말 것.** 재측정을 요청하는 게 맞다.

## tipping — 전복 위험 (FR-103)

무게중심이 **지지면(파렛트)** 을 벗어나는지로 판정한다. 편하중과 다른 질문이다.

- `support_offset` = |화물 무게중심 − 파렛트 중심| ÷ (파렛트 반폭).
  **1.0이면 무게중심이 파렛트 끝** = 물리적 전복 한계.
- `level`: `safe`(<0.60) / `warning`(0.60~0.85) / `danger`(≥0.85).
  종횡비 ≥1.5이거나 화물이 파렛트 밖으로 크게 나가면 한 단계 격상.
- `static_stable`: **정지 상태에서 넘어지는가**. `level`은 **운반 기준**이라 다를 수 있다 —
  세워두면 안 넘어져도(`static_stable: true`) 지게차로 옮기기엔 부적합할 수 있다
  (실측 사례: 여유 20%에 하단 박스 42%가 파렛트 밖).

⚠️ 임계 0.60/0.85는 물리 한계 전에 안전 여유를 둔 **공학적 판단**이며, 실측 표본은
5건뿐이다. 지게차 실주행(Sprint 3) 검증 후 조정될 수 있다.

## load_balance — 편하중 (FR-104)

- `ratio_x` = (화물 무게중심 − 파렛트 중심) ÷ 화물 반폭. **부호 있음**(+오른쪽).
- `|ratio_x| > threshold(0.3)`이면 `eccentric: true`.
- `ratio_y`는 **항상 null** — 정면 뷰에서 위아래는 편하중 축이 아니다.

## box_measurements — 박스별 치수

`dimensions`는 적재물 **전체 외곽(hull)** 하나지만, 박스를 개별로 배치한다면 이 배열을 쓴다.

```jsonc
{ "bbox_px": [1078,433,422,259], "score": 0.97,
  "height_cm": 30.0, "width_cm": 49.1,
  "miniature_height_mm": 30.0, "miniature_width_mm": 49.1 }
```

⚠️ 거리계가 값을 하나만 주므로 **모든 박스가 카메라에서 비슷한 거리(같은 앞면)** 여야
정확하다. 앞뒤로 벌어지면 뒤쪽 박스의 오차가 커진다.

## 정확도 (실측 근거)

| 항목 | 결과 | 조건 |
|---|---|---|
| 치수 오차 | **평균 0.66mm / 최대 2.10mm** (미니어처) | 단일 박스 54/54 통과, 거리 129~294cm |
| 박스별 치수 | 98.1% 통과 | 다중 박스 |
| 박스·파렛트 검출 | mAP@0.5 **0.9898** | 리그 평가셋 30장 |

KPI는 미니어처 ≤4mm. 상세는 `docs/ai/station-dim-eval-plan.md`, `docs/ai/rig-eval-map.md`.

**측정 조건**: 화물을 **프레임 중앙**에 둘 것(가장자리는 렌즈 왜곡으로 오차↑),
사람은 프레임 밖, 거리계 빔이 화물 앞면을 정조준.

## 샘플 얻기

```
python src/station/serve.py --once --out sample.json          # 라이브
python src/station/serve.py --once --image <사진> --distance 200   # 사진으로
```

## 전달 방식 — 확정(REST)

**확정됐다.** 측정 데스크탑이 `POST /api/stations/measurements`로 직접 호출한다.
MQTT(`fast/station/+/measurement`)는 **폐기**됐고 백엔드에서 구독·라우팅·DTO가 모두 제거됐다.
측정 데스크탑은 **DB에 직접 접속하지 않는다** — 이 REST API가 유일한 저장 경로다.

데스크탑 쪽 구현 완료 (2026-07-31, `station/rest_client.py`):

```bash
STATION_API_BASE=http://<백엔드> python src/station/serve.py --once --publish
```

1. ✅ 원본 JSON → REST 요청 6필드로 축약 (`to_request`)
2. ✅ **`height_cm` ÷ 100** 으로 cm → m 변환
3. ✅ **세션 개설·종료 자동화**(2026-07-31) — `--cargo-id`를 주면 데스크탑이 직접 연다. 아래 참조
4. ✅ 409 `STATION_MEASUREMENT_ID_DUPLICATED`는 **성공으로 취급**(이미 저장됨, 재전송 불필요)

> ⚠️ **`cargoHeight`에 `total_height_cm`을 넣지 말 것.** 백엔드가 적재 판단에서 파렛트
> 0.12m를 따로 더하므로(`requiredHeight = cargoHeight + 0.12 + clearance`) 총높이를 보내면
> 파렛트를 두 번 더한다. 단위 변환과 이 구분은 `tests/test_rest_client.py`가 회귀 검증한다.

**서버 확인 완료 (2026-08-03 갱신)**: 백엔드는 **EC2 `http://i15a304.p.ssafy.io:8080`**
에 배포돼 있다. 실물 리그로 전 구간(세션 → 측정 저장 201 → 자동 해제 → 조회)을 돌려
확인했다 — `cargoHeight 0.585`(화물만) · `tippingLevel SAFE` · `overhangRatio 0.0` ·
`placementEligible true`.

> ⚠️ **종전 주소 `70.12.246.250:8080`(김재원 노트북)은 죽었다.** 2026-07-31 저녁에
> 접속 불가를 확인했고 배포는 EC2로 갔다. 이 문서가 그 주소를 계속 가리키고 있어
> 2026-08-03에 고쳤다 — **주소는 문서 말고 실측을 믿을 것.**

## 세션 — 단일 설비 뮤텍스

백엔드는 `station_state`의 `active_session_id` **한 행**으로 설비 점유를 지킨다. 열려
있는 동안 다른 화물은 세션을 못 연다(409 `STATION_ALREADY_OCCUPIED`).

```bash
STATION_API_BASE=http://i15a304.p.ssafy.io:8080 \
  python src/station/serve.py --once --publish --cargo-id cargo-1
```

### ⚠️ `--cargo-id` 없이 보내면 남의 화물에 붙는다

측정 요청에는 **cargoId가 없다.** 세션을 열 때 준 화물에 귀속된다. 그래서 잘못된
세션에 보내면 **그 화물에 조용히 기록되고, 사후에 알아낼 방법이 없다.**

> **2026-08-03 갱신 — `sessionId`가 필수가 되면서 오귀속 구멍이 막혔다.**
> 종전에는 백엔드가 `findActiveSession()`으로 *현재* 활성 세션을 찾아 붙였다. TTL로
> 세션 A가 풀리고 B가 열린 뒤 도착한 **A의 늦은 측정이 B에 귀속**되는 문제가 있었다.
> 지금은 요청에 `sessionId`를 실어야 하고 활성 세션과 다르면 409
> `STATION_SESSION_MISMATCH`로 거부된다.
>
> ⚠️ **불일치로 거부됐다고 새 sessionId로 바꿔 재전송하면 안 된다** — 막으려던
> 오귀속을 그대로 되살린다. 측정 시점의 값을 유지할 것.

→ **측정 데스크탑이 자기 세션을 열고 자기가 닫는다.** ("누가 여는지"의 답이다.)

### 세션은 측정 **앞에** 연다

백엔드 문서상 정상 흐름("세션 시작 → 측정 → 결과 등록")을 그대로 따른다. 세션이
**"지금 이 화물을 측정 중"** 이라는 뜻을 갖고, 둘을 얻는다:

- 관제가 `GET /api/stations/sessions/active`로 **설비 점유를 실시간 표시**할 수 있다
- 설비가 이미 점유 중이면 **측정을 시작하기 전에** 409로 튕겨 헛수고를 막는다

전송 직전에 여는 배치도 검토했다(잠김 구간이 요청 한 번으로 줄어든다). 하지만 그러면
세션이 몇 밀리초만 존재해 위 둘을 다 잃는다. 실패 시 `unreliable` 측정을 남겨 자동
해제하는 절충안도 있었으나, **측정 실패 행을 DB에 쌓지 않기로** 했다(2026-07-31 결정).

### ~~세션은 스스로 안 풀린다~~ → TTL이 도입됐다 (2026-08-03 갱신)

> **아래 서술은 TTL 도입 전(~2026-07-31) 기준이다.** 지금은 백엔드가 세션을 자동
> 해제하므로 "영구 잠김"은 발생하지 않는다. 배경으로 남겨둔다.
>
> | 항목 | 현재 |
> |---|---|
> | 활성 세션 TTL | `STATION_SESSION_TTL_SECONDS` **기본 60초** |
> | MOVE 결과 대기 TTL | `STATION_MOVE_TTL_SECONDS` 기본 300초 |
> | 정리 주기 | `STATION_SESSION_CLEANUP_INTERVAL_MS` 기본 5초 |
> | 측정 저장 시 | **세션이 자동 해제된다.** 이후 `DELETE`는 409 `STATION_SESSION_NOT_ACTIVE` — **정상 종료로 처리할 것** |
> | TTL 초과 시 | 세션 해제 + 작업 `FAILED`. **재측정은 없다** |
>
> ⚠️ **TTL 60초 안에 측정이 저장돼야 한다.** 여유는 충분하다 — 세션 창 상한이 정지
> 대기 ≤5초(`STILL_TIMEOUT_S`) + 추론 ≤1.5초(`DEFAULT_TIMEOUT`) + REST ~0.2초로
> **6초 이내**다(2026-08-03 실측). 다만 `--once`로 잰 총 소요 10초에는 파이썬 기동과
> 105MB ONNX 로드가 포함돼 있으니 **그 값을 TTL 예산으로 쓰지 말 것** — 상시 모드
> (`--listen`)에서는 세션을 열기 전에 끝나 있다.

백엔드에 **TTL·자동 만료가 없다.** 게다가 종료는 **측정이 저장된 뒤에만** 된다
(409 `STATION_MEASUREMENT_NOT_COMPLETED`). 전송이 실패한 채 끝나면 설비가 잠긴 채 남고
**아무도 새 측정을 시작할 수 없다.**

`measurement_session` 컨텍스트 매니저가 보장하는 범위는 이만큼이다:

| 종료 경로 | 닫히나 |
|---|---|
| 정상 종료 · 예외 · Ctrl-C | ✅ |
| `SIGTERM`(kill, 서비스 정지) | ✅ 핸들러로 예외 전환 |
| `SIGKILL`(kill -9) · 전원 차단 | ❌ 불가능 |
| **측정 도중 예외**(카메라 미개방·해상도 불일치·모델 없음) | ❌ 백엔드가 종료를 거부 |
| 측정 전송 실패 후 종료 | ❌ 위와 같음 |

세션을 측정 앞에 열기로 한 대가가 가운데 줄이다 — 그 구간이 수 초로 늘어난다.
`serve.py`는 이때 종료 코드 **2**로 끝나 잠김을 알린다. 코드 체계는 이렇다:

| 코드 | 뜻 | 볼 곳 |
|---|---|---|
| `0` | 성공 | — |
| `1` | **재려고 했는데 실패** (검출 없음·전송 실패) | 화물 배치·조명·검출 |
| `2` | **내가 연 세션이 안 풀림** | `--release-session [--abandon]` |
| `3` | **세션을 못 열어 시작조차 못 함** (409 점유·백엔드 불통) | 설비 점유 여부·백엔드 연결 |

⚠️ `1`과 `3`은 **운영자가 할 일이 다르다.** 종전에는 둘 다 `1`이라 로그 끝만
보고는 "재봤는데 안 나온 건지, 아예 못 재본 건지"를 가릴 수 없었다
(2026-08-03 분리).

마지막 셋은 사람이 푼다:

```bash
python src/station/serve.py --release-session            # 조회 후 종료 시도
python src/station/serve.py --release-session --abandon  # 측정 실패를 기록하고 세션 종료
```

`--abandon`은 `unreliable` 측정을 하나 남겨 잠금을 푼다. **없는 측정을 지어내는 것이
아니라 "이 세션은 측정에 실패했다"를 기록하는 것**이다.

> 백엔드는 측정 요청·활성 세션에 TTL을 적용한다. 클라이언트가 `kill -9` 또는 전원 차단으로
> 종료돼도 TTL이 지나면 세션과 연결 작업을 자동 정리하므로 별도 강제 해제 API는 사용하지 않는다.

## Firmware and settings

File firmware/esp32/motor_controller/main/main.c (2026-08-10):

#include "task_comm.h"
#include "task_imu.h"
#include "task_motor.h"
#include "task_telemetry.h"
#include "task_tof.h"
#include "task_encoder.h"
#include "stepper_motor.h"
#include "config.h"

#include "esp_err.h"
#include "esp_log.h"
#include "freertos/FreeRTOS.h"
#include "freertos/task.h"

static const char *TAG = "MAIN";

static esp_err_t wait_for_stepper_idle(
    stepper_motor_status_t *status
)
{
    do {
        esp_err_t result = stepper_motor_get_status(status);

        if (result != ESP_OK) {
            return result;
        }

        if (status->busy) {
            vTaskDelay(pdMS_TO_TICKS(
                STEPPER_MOTOR_PROFILE_PERIOD_MS
            ));
        }
    } while (status->busy);

    return ESP_OK;
}

static esp_err_t run_guarded_homing_sequence(void)
{
    stepper_motor_status_t status;

    ESP_LOGW(TAG, "Starting guarded lower-limit homing");
    esp_err_t result = stepper_motor_home();

    if (result != ESP_OK) {
        return result;
    }

    result = wait_for_stepper_idle(&status);

    if (result != ESP_OK) {
        return result;
    }

    if (!status.homed) {
        ESP_LOGE(TAG, "Lower-limit homing did not establish home");
        return ESP_FAIL;
    }

    if (!status.lower_limit_active) {
        ESP_LOGI(TAG, "Homing completed with lower limit released");
        return ESP_OK;
    }

    ESP_LOGI(
        TAG,
        "Lower limit active; backing off after %u ms",
        STEPPER_MOTOR_HOME_BACKOFF_DELAY_MS
    );
    vTaskDelay(pdMS_TO_TICKS(
        STEPPER_MOTOR_HOME_BACKOFF_DELAY_MS
    ));

    result = stepper_motor_move_steps(
        STEPPER_MOTOR_DIRECTION_EXTEND,
        STEPPER_MOTOR_HOME_BACKOFF_STEPS,
        STEPPER_MOTOR_HOME_BACKOFF_RATE_SPS,
        STEPPER_MOTOR_HOME_BACKOFF_ACCEL_SPS2
    );

    if (result != ESP_OK) {
        return result;
    }

    result = wait_for_stepper_idle(&status);

    if (result != ESP_OK) {
        return result;
    }

    if (status.lower_limit_active) {
        ESP_LOGE(
            TAG,
            "Backoff completed but lower limit is still active"
        );
        return ESP_FAIL;
    }

    ESP_LOGI(
        TAG,
        "Homing backoff completed: %u steps, lower limit released",
        STEPPER_MOTOR_HOME_BACKOFF_STEPS
    );
    return ESP_OK;
}

void app_main(void)
{
    ESP_LOGI(TAG, "Forklift motor controller starting");

    ESP_ERROR_CHECK(stepper_motor_init());
    ESP_ERROR_CHECK(motor_task_start());
    ESP_ERROR_CHECK(comm_task_start());

    /*
     * The sensor uplink is best-effort: a missing USB host or a missing gyro
     * must never keep the drive and fork from running. Start the uplink before
     * homing so its log output already goes through the USB driver, and start
     * the IMU afterwards so bias is measured with the fork at rest.
     */
    esp_err_t telemetry_result = telemetry_task_start();

    if (telemetry_result != ESP_OK) {
        ESP_LOGE(TAG, "Telemetry uplink unavailable: %s",
                 esp_err_to_name(telemetry_result));
    }

#if STEPPER_MOTOR_STARTUP_HOME_ENABLED
    for (int seconds = 10; seconds > 0; --seconds) {
        ESP_LOGW(TAG,
                 "Stepper homing starts in %d second(s); "
                 "keep power cutoff ready",
                 seconds);
        vTaskDelay(pdMS_TO_TICKS(1000));
    }
    /*
     * ⚠️ **여기에 ESP_ERROR_CHECK 를 쓰지 않는다.**
     *
     * 2026-08-09: 드라이버 열보호로 포크가 안 내려가 호밍이 실패했는데,
     * ESP_ERROR_CHECK 가 패닉을 내 보드가 리셋되고 10 초 뒤 또 호밍을 걸었다.
     * 뜨거운 드라이버에 통전이 끊기지 않고 반복돼 **과열을 오히려 키웠다.**
     *
     * 호밍 실패는 치명적이지 않다 — 포크 높이 기준만 없는 상태이고, 주행·통신은
     * 그대로 살아 있어야 사람이 원인을 볼 수 있다. 그래서 드라이버를 끄고
     * 시끄럽게 남긴 뒤 계속 부팅한다. 원인이 풀리면 `/fork/command` 의 `HOME`
     * 으로 다시 걸면 된다.
     */
    esp_err_t homing_result = run_guarded_homing_sequence();

    if (homing_result != ESP_OK) {
        ESP_LOGE(
            TAG,
            "Startup homing failed: %s — driver disabled, fork height "
            "is UNKNOWN. Check the lower-limit wiring, driver temperature "
            "(TMC2209 shuts down when hot), and whether the fork is stuck. "
            "Re-run with the HOME fork command once fixed.",
            esp_err_to_name(homing_result)
        );
        (void)stepper_motor_stop();
    }
#elif STEPPER_MOTOR_STARTUP_TEST_ENABLED
    for (int seconds = 10; seconds > 0; --seconds) {
        ESP_LOGW(TAG,
                 "Stepper retract test starts in %d second(s); "
                 "keep power cutoff ready",
                 seconds);
        vTaskDelay(pdMS_TO_TICKS(1000));
    }
    ESP_LOGW(TAG, "Starting load-free stepper retract test");
    ESP_ERROR_CHECK(stepper_motor_move_steps(
        STEPPER_MOTOR_DIRECTION_RETRACT,
        STEPPER_MOTOR_STARTUP_TEST_STEPS,
        STEPPER_MOTOR_STARTUP_TEST_RATE_SPS,
        STEPPER_MOTOR_DEFAULT_ACCEL_SPS2));
#endif

    if (telemetry_result == ESP_OK) {
        esp_err_t imu_result = imu_task_start();

        if (imu_result != ESP_OK) {
            ESP_LOGE(TAG, "IMU unavailable, continuing without gyro: %s",
                     esp_err_to_name(imu_result));
        }

        /*
         * Started last: each sensor takes about a second to accept its firmware
         * over I2C, and nothing else should wait on that.
         */
        esp_err_t tof_result = tof_task_start();

        if (tof_result != ESP_OK) {
            ESP_LOGE(TAG,
                     "Front ToF unavailable, continuing without it: %s",
                     esp_err_to_name(tof_result));
        }

        esp_err_t encoder_result = encoder_task_start();

        if (encoder_result != ESP_OK) {
            ESP_LOGE(TAG,
                     "Wheel encoder unavailable, continuing without it: %s",
                     esp_err_to_name(encoder_result));
        }
    } else {
        ESP_LOGW(TAG, "Skipping IMU and ToF start; nowhere to publish");
    }

    ESP_LOGI(TAG, "All tasks created successfully");
}

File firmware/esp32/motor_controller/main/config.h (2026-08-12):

#ifndef CONFIG_H
#define CONFIG_H

#include "driver/gpio.h"

/* FreeRTOS */
#define MOTOR_TASK_STACK_SIZE           4096
#define MOTOR_TASK_PRIORITY             5

#define COMM_TASK_STACK_SIZE            3072
#define COMM_TASK_PRIORITY              4

/*
 * A marginal I2C connector must not cost the whole vehicle. Actuator bring-up
 * is retried at boot, and keeps being retried afterwards, so a cable that is
 * reseated recovers without a reboot.
 */
#define MOTOR_INIT_RETRY_COUNT          5U
#define MOTOR_INIT_RETRY_DELAY_MS       500U

/*
 * ToF(VL53L8CX) 초기화 재시도. `vl53l8cx_pair.c` 가 쓴다.
 *
 * ⚠️ 이 두 값은 원래 **젯슨의 로컬 config.h 에만** 있었고, 2026-08-07 에 노트북
 * 사본을 젯슨으로 복사하면서 덮어써 사라졌다(빌드가 undeclared 로 깨졌다). 여기
 * 값은 모터 쪽 재시도(5회/500ms)를 따라 복원한 것이라 **원래 값과 다를 수 있다.**
 * 담당자가 확인해 고칠 것.
 */
#define TOF_INIT_RETRY_COUNT            5U
#define TOF_INIT_RETRY_DELAY_MS         500U
#define MOTOR_RECOVERY_PERIOD_MS        5000U

/*
 * Sampling must not be delayed by telemetry, so the IMU task runs at a high
 * priority on core 0 while the USB uplink drains its queue on core 1.
 */
#define IMU_TASK_STACK_SIZE             4096
#define IMU_TASK_PRIORITY               10
#define IMU_TASK_CORE_ID                0

#define TELEMETRY_TASK_STACK_SIZE       4096
#define TELEMETRY_TASK_PRIORITY         4
#define TELEMETRY_TASK_CORE_ID          1

/* Fork lift stepper motor (BIGTREETECH TMC2209 V1.1, STEP/DIR mode) */
#define STEPPER_MOTOR_STEP_GPIO           GPIO_NUM_4
#define STEPPER_MOTOR_DIR_GPIO            GPIO_NUM_5
#define STEPPER_MOTOR_ENABLE_GPIO         GPIO_NUM_6
#define STEPPER_MOTOR_LOWER_LIMIT_GPIO    GPIO_NUM_7
#define STEPPER_MOTOR_ENABLE_ACTIVE_LEVEL 0
#define STEPPER_MOTOR_LOWER_LIMIT_ACTIVE_LEVEL 1
#define STEPPER_MOTOR_EXTEND_DIR_LEVEL    1

#define STEPPER_MOTOR_TIMER_RESOLUTION_HZ 1000000U
#define STEPPER_MOTOR_STEP_PULSE_HIGH_US  5U
#define STEPPER_MOTOR_PROFILE_PERIOD_MS   10U
#define STEPPER_MOTOR_TASK_STACK_SIZE     3072U
#define STEPPER_MOTOR_TASK_PRIORITY       5U

#define STEPPER_MOTOR_START_RATE_SPS      200U
/*
 * 동작 후 드라이버를 켜둘 것인가(유지 토크). 1 이면 켜둔다.
 *
 * 0 이면 포크가 중력으로 내려앉는다 — 2026-08-07 에 높이를 맞춰도 몇 분 뒤 달라졌다.
 * 1 은 대기 전류를 쓰므로 드라이버가 따뜻해진다.
 */
#define STEPPER_MOTOR_HOLD_AFTER_MOTION   1

/*
 * 유지 토크를 **얼마나 오래** 붙잡을 것인가. 0 이면 무기한(종전 동작).
 *
 * ⚠️ 2026-08-09 에 무기한 유지로 **TMC2209 가 만질 수 없을 만큼 뜨거워졌다.**
 * 열보호가 걸리면 포크가 안 내려가고, 그러면 부팅 호밍이 하한 스위치에 영영
 * 닿지 못해 150 초를 갈다 실패한다 — 그 사이 모든 포크 명령이
 * `ESP_ERR_INVALID_STATE` 로 거부된다.
 *
 * 30 초면 "정렬 직전에 높이를 맞춰 두는" 용도는 그대로 살고, 방치했을 때의
 * 상시 통전은 사라진다. 정렬 한 회차가 30 초를 넘으면 늘릴 것.
 *
 * ⚠️ 이건 **증상 완화지 근본 해결이 아니다.** 근본은 드라이버 Vref(전류 제한)가
 * 미니어처 포크에 견줘 과하다는 것이다. Vref 를 낮추면 유지 중에도 안 뜨겁다.
 */
#define STEPPER_MOTOR_HOLD_TIMEOUT_MS     30000U

#define STEPPER_MOTOR_DEFAULT_RATE_SPS    5000U
#define STEPPER_MOTOR_DEFAULT_ACCEL_SPS2  10000U
#define STEPPER_MOTOR_DEFAULT_MOVE_STEPS  19200U
#define STEPPER_MOTOR_HOMING_RATE_SPS     2000U
#define STEPPER_MOTOR_HOMING_ACCEL_SPS2   600U
/*
 * 호밍이 하한 스위치를 못 찾았을 때 포기하는 지점.
 *
 * 300000 스텝은 2000 sps 에서 **150 초**다. 스위치가 안 눌리는 상황(배선 끊김·
 * 드라이버 열보호·포크 걸림)에서 그 150 초를 통째로 갈아넣고서야 실패를 알았다.
 * 그동안 포크 명령은 전부 거부되고 모터는 계속 통전된다 — 과열 상황에서는
 * 이 시간이 그대로 손해다.
 *
 * 60000 = 30 초. 실제 스트로크보다 넉넉하되 실패를 빨리 알리는 값으로 잡았다.
 * ⚠️ 실제 최대 스트로크를 재본 값이 아니다 — 정상 호밍이 이 값에 가깝게
 * 걸리면 늘릴 것.
 */
#define STEPPER_MOTOR_HOMING_MAX_STEPS    60000U
#define STEPPER_MOTOR_HOME_BACKOFF_DELAY_MS 500U
/*
 * 호밍 뒤 하한에서 올라오는 양 = **포크의 기준 높이**다. 미니어처 파렛트는 총높이
 * 14mm(상판 2 + 구멍 10 + 하판 2)라 여기서 몇 mm만 어긋나도 포크가 구멍이 아니라
 * 상판이나 하판을 민다.
 *
 * 1600 -> 1200 -> 7500 -> **6500** (2026-08-07). 앞의 값들은 눈대중이었고, 6500 은 하한에서
 * 스텝을 실어 올려가며 **실물로 맞춘 값**이다(`/fork/command` 에 "UP 7500" 뒤
 * "DOWN 1000").
 *
 * ⚠️ **이 상수는 부팅 호밍에서만 쓰인다.** `/fork/command` 의 `HOME` 은 하한까지만
 * 내려가고 거기서 멈춘다(백오프 없음) — 그래서 손으로 맞출 때는 `HOME` 뒤에
 * "UP 6500" 을 따로 보내야 같은 높이가 된다. 2026-08-07 에 이걸 모르고 HOME 만
 * 걸어놓고 "높이가 맞다" 고 판단했다.
 *
 * ⚠️ 이 상수를 고치기 전까지는 몇 mm 를 옮기려고 매번 재플래시했다. 지금은 프레임에
 * 스텝을 실을 수 있으므로, 다시 맞출 때는 하한(HOME 직후 DOWN)에서 "UP <스텝>" 으로
 * 찾은 뒤 그 숫자를 여기 적는다.
 */
#define STEPPER_MOTOR_HOME_BACKOFF_STEPS  6500U
#define STEPPER_MOTOR_HOME_BACKOFF_RATE_SPS 500U
#define STEPPER_MOTOR_HOME_BACKOFF_ACCEL_SPS2 300U
#define STEPPER_MOTOR_LIMIT_DEBOUNCE_MS   20U

#define STEPPER_MOTOR_MIN_RATE_SPS        20U
#define STEPPER_MOTOR_MAX_RATE_SPS        6000U
#define STEPPER_MOTOR_MAX_ACCEL_SPS2      20000U
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

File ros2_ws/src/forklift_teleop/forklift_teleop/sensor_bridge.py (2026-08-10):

"""Publish IMU and front ToF data from the ESP32 USB telemetry uplink.

One node rather than several because ``/dev/ttyACM0`` can only be opened by a
single process, and every sensor frame arrives interleaved on that one stream.

This stays separate from ``uart_teleop_bridge`` on purpose: the command link is
a different device file (``/dev/ttyTHS1``), so telemetry cannot delay commands
and the working tele-operation path is untouched.
"""

import collections
import math
import struct
import threading
import time
from typing import Optional

import rclpy
from rcl_interfaces.msg import ParameterDescriptor
from rclpy.node import Node
from geometry_msgs.msg import TwistWithCovarianceStamped
from sensor_msgs.msg import Imu, PointCloud2, PointField
import serial

from forklift_teleop.sensor_protocol import (
    TOF_STATUS_VALID,
    TOF_STATUS_VALID_LOW_CONFIDENCE,
    TOF_ZONE_COUNT,
    ClockOffsetTracker,
    EncoderFrame,
    ImuFrame,
    ImuStatusFrame,
    TofFrame,
    TofStatusFrame,
    parse_sensor_line,
)

MDPS_TO_RAD_PER_SEC = (math.pi / 180.0) / 1000.0
ENCODER_NOMINAL_RATE_HZ = 50.0
# Large but finite: zero on an unmeasured axis reads as a perfect measurement
# of no motion and would pin the filter to it.
TOF_UNUSED_VARIANCE = 1e6

# ROS convention for "this field is not measured".
ORIENTATION_UNUSED = -1.0

# Large but finite: the EKF must ignore these axes without treating the
# covariance as degenerate.
UNTRUSTED_VARIANCE = 1e6

# How long the reader parks when the port has nothing. Short enough that the
# kernel tty buffer never builds up at the 13 kB/s this link carries.
READER_IDLE_SLEEP_SEC = 0.002

TOF_GRID_SIDE = 8
TOF_SENSOR_NAMES = ("left", "right")


def _cloud(stamp_ns: int, frame_id: str, payload: bytes, count: int
           ) -> PointCloud2:
    message = PointCloud2()
    message.header.stamp.sec = stamp_ns // 1_000_000_000
    message.header.stamp.nanosec = stamp_ns % 1_000_000_000
    message.header.frame_id = frame_id
    # Unordered: invalid zones are dropped rather than filled with NaN, so the
    # costmap never sees a phantom return.
    message.height = 1
    message.width = count
    message.fields = [
        PointField(name="x", offset=0, datatype=PointField.FLOAT32, count=1),
        PointField(name="y", offset=4, datatype=PointField.FLOAT32, count=1),
        PointField(name="z", offset=8, datatype=PointField.FLOAT32, count=1),
    ]
    message.is_bigendian = False
    message.point_step = 12
    message.row_step = 12 * count
    message.data = bytes(payload)
    message.is_dense = True
    return message


class SensorBridge(Node):
    def __init__(self) -> None:
        super().__init__("sensor_bridge")

        self.declare_parameter("serial_port", "/dev/ttyACM0")
        self.declare_parameter("baud_rate", 115200)
        self.declare_parameter("imu_topic", "/imu/data")
        self.declare_parameter("imu_frame_id", "imu_link")
        self.declare_parameter("read_rate_hz", 200.0)
        self.declare_parameter("gyro_z_sign", 1)
        self.declare_parameter("yaw_rate_stddev", 0.02)
        self.declare_parameter("status_log_period_sec", 10.0)

        self.declare_parameter("tof_enabled", True)
        self.declare_parameter("tof_topics", ["/tof/left/points",
                                              "/tof/right/points"])
        self.declare_parameter("tof_frame_ids", ["tof_left_link",
                                                 "tof_right_link"])
        # Square field of view in degrees, spread over the 8x8 grid. Check this
        # against the datasheet: get it wrong and every bearing is wrong.
        self.declare_parameter("tof_fov_deg", 45.0)
        # Which way the zone grid runs relative to the sensor frame. A mirrored
        # column or row order is a reflection, not a rotation, so unlike a
        # mounting offset it cannot be corrected by the static transform.
        # Verify with an object at a known bearing before trusting the cloud.
        self.declare_parameter("tof_azimuth_sign", 1)
        self.declare_parameter("tof_elevation_sign", 1)
        # True when the board is turned 90 degrees about its optical axis, so
        # the grid rows carry bearing and the columns carry height.
        self.declare_parameter("tof_transpose_zones", False)
        self.declare_parameter("tof_accept_low_confidence", False)
        self.declare_parameter("tof_min_range_m", 0.02)
        self.declare_parameter("tof_max_range_m", 3.5)
        # Mount height above the floor, per sensor, in metres. The sensors are
        # mounted level, so a point below -(height - margin) in the sensor frame
        # is the floor: no transform lookup is needed to recognise it.
        self.declare_parameter("tof_mount_height_m", [0.07, 0.07])
        self.declare_parameter("tof_ground_margin_m", 0.02)
        self.declare_parameter("tof_pitch_deg", [0.0, 0.0])
        # A zone must repeat before it is believed. Set hits to 1 to disable.
        self.declare_parameter("tof_persistence_frames", 3)
        self.declare_parameter("tof_persistence_hits", 2)
        self.declare_parameter("tof_persistence_tolerance_m", 0.05)
        # Range at which a zone that keeps reporting nothing is emitted as a
        # clearing ray. 0 disables. See _publish_tof for why this must sit
        # between the costmap's obstacle_max_range and raytrace_max_range.
        self.declare_parameter("tof_clear_range_m", 2.2)
        self.declare_parameter("tof_clear_persistence_frames", 3)
        self.declare_parameter("tof_empty_statuses", [0, 255])
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

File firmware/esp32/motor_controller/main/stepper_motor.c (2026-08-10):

#include "stepper_motor.h"

#include <stdbool.h>
#include <stdint.h>

#include "config.h"

#include "driver/gpio.h"
#include "driver/gptimer.h"
#include "esp_attr.h"
#include "esp_check.h"
#include "esp_err.h"
#include "esp_log.h"

#include "freertos/FreeRTOS.h"
#include "freertos/task.h"

static const char *TAG = "STEPPER_MOTOR";

typedef struct {
    volatile bool busy;
    volatile bool timer_running;
    volatile bool stop_requested;
    volatile bool step_high;
    volatile bool timer_error;
    volatile bool homing;
    volatile bool lower_limit_hit;
    volatile stepper_motor_direction_t direction;
    volatile uint32_t total_steps;
    volatile uint32_t completed_steps;
    volatile uint32_t current_rate_sps;
    volatile uint32_t target_rate_sps;
    volatile uint32_t acceleration_sps2;
    volatile uint32_t step_period_us;
} stepper_motor_motion_t;

static gptimer_handle_t s_step_timer = NULL;
static TaskHandle_t s_profile_task = NULL;
static stepper_motor_motion_t s_motion = {0};
static portMUX_TYPE s_motion_lock = portMUX_INITIALIZER_UNLOCKED;
static bool s_initialized = false;
static volatile bool s_homed = false;
static volatile bool s_driver_enabled = false;
/* 0 = 유지 해제 예약 없음. 그 외에는 이 틱에 드라이버를 끈다. */
static volatile TickType_t s_hold_release_deadline = 0;

bool stepper_motor_is_lower_limit_active(void)
{
    return gpio_get_level(STEPPER_MOTOR_LOWER_LIMIT_GPIO) ==
        STEPPER_MOTOR_LOWER_LIMIT_ACTIVE_LEVEL;
}

static uint32_t integer_sqrt_u64(uint64_t value)
{
    uint64_t result = 0;
    uint64_t bit = UINT64_C(1) << 62;

    while (bit > value) {
        bit >>= 2;
    }

    while (bit != 0) {
        if (value >= result + bit) {
            value -= result + bit;
            result = (result >> 1) + bit;
        } else {
            result >>= 1;
        }

        bit >>= 2;
    }

    return result > UINT32_MAX ? UINT32_MAX : (uint32_t)result;
}

static uint32_t rate_to_period_us(uint32_t rate_sps)
{
    if (rate_sps < STEPPER_MOTOR_MIN_RATE_SPS) {
        rate_sps = STEPPER_MOTOR_MIN_RATE_SPS;
    }

    uint32_t period_us =
        STEPPER_MOTOR_TIMER_RESOLUTION_HZ / rate_sps;
    uint32_t minimum_period_us =
        STEPPER_MOTOR_STEP_PULSE_HIGH_US * 2U;

    return period_us < minimum_period_us
        ? minimum_period_us
        : period_us;
}

static void stepper_motor_set_enabled(bool enabled)
{
    int level = enabled
        ? STEPPER_MOTOR_ENABLE_ACTIVE_LEVEL
        : !STEPPER_MOTOR_ENABLE_ACTIVE_LEVEL;

    gpio_set_level(STEPPER_MOTOR_ENABLE_GPIO, level);
    s_driver_enabled = enabled;

    if (!enabled) {
        s_hold_release_deadline = 0;
    }
}

static bool IRAM_ATTR stepper_motor_notify_profile_task_from_isr(void)
{
    BaseType_t high_priority_task_woken = pdFALSE;

    if (s_profile_task != NULL) {
        vTaskNotifyGiveFromISR(
            s_profile_task,
            &high_priority_task_woken
        );
    }

    return high_priority_task_woken == pdTRUE;
}

static bool IRAM_ATTR stepper_motor_step_alarm_callback(
    gptimer_handle_t timer,
    const gptimer_alarm_event_data_t *event_data,
    void *user_context
)
{
    (void)user_context;

    uint32_t next_interval_us;

    if (s_motion.direction == STEPPER_MOTOR_DIRECTION_RETRACT &&
        stepper_motor_is_lower_limit_active()) {
        gpio_set_level(STEPPER_MOTOR_STEP_GPIO, 0);
        s_motion.step_high = false;
        s_motion.lower_limit_hit = true;
        s_motion.busy = false;
        s_homed = true;
        return stepper_motor_notify_profile_task_from_isr();
    }

    if (s_motion.stop_requested) {
        gpio_set_level(STEPPER_MOTOR_STEP_GPIO, 0);
        s_motion.step_high = false;
        s_motion.busy = false;
        return stepper_motor_notify_profile_task_from_isr();
    }

    if (!s_motion.step_high) {
        if (s_motion.completed_steps >= s_motion.total_steps) {
            s_motion.busy = false;
            return stepper_motor_notify_profile_task_from_isr();
        }

        gpio_set_level(STEPPER_MOTOR_STEP_GPIO, 1);
        s_motion.step_high = true;
        s_motion.completed_steps++;
        next_interval_us = STEPPER_MOTOR_STEP_PULSE_HIGH_US;
    } else {
        gpio_set_level(STEPPER_MOTOR_STEP_GPIO, 0);
        s_motion.step_high = false;

        if (s_motion.completed_steps >= s_motion.total_steps) {
            s_motion.busy = false;
            return stepper_motor_notify_profile_task_from_isr();
        }

        uint32_t period_us = s_motion.step_period_us;
        next_interval_us =
            period_us > STEPPER_MOTOR_STEP_PULSE_HIGH_US
                ? period_us - STEPPER_MOTOR_STEP_PULSE_HIGH_US
                : STEPPER_MOTOR_STEP_PULSE_HIGH_US;
    }

    gptimer_alarm_config_t alarm_config = {
        .alarm_count = event_data->alarm_value + next_interval_us,
        .flags.auto_reload_on_alarm = false
    };

    if (gptimer_set_alarm_action(timer, &alarm_config) != ESP_OK) {
        gpio_set_level(STEPPER_MOTOR_STEP_GPIO, 0);
        s_motion.step_high = false;
        s_motion.timer_error = true;
        s_motion.busy = false;
        return stepper_motor_notify_profile_task_from_isr();
    }

    return false;
}

static uint32_t stepper_motor_calculate_profile_rate(void)
{
    uint32_t completed = s_motion.completed_steps;
    uint32_t total = s_motion.total_steps;
    uint32_t target = s_motion.target_rate_sps;
    uint32_t acceleration = s_motion.acceleration_sps2;
    uint32_t remaining = completed < total ? total - completed : 0;
    uint64_t start_rate_squared =
        (uint64_t)STEPPER_MOTOR_START_RATE_SPS *
        STEPPER_MOTOR_START_RATE_SPS;

    uint32_t acceleration_limit = integer_sqrt_u64(
        start_rate_squared +
        (uint64_t)2U * acceleration * completed
    );
    uint32_t deceleration_limit = integer_sqrt_u64(
        start_rate_squared +
        (uint64_t)2U * acceleration * remaining
    );

    uint32_t rate = target;

    if (rate > acceleration_limit) {
        rate = acceleration_limit;
    }

    if (rate > deceleration_limit) {
        rate = deceleration_limit;
    }

    if (rate < STEPPER_MOTOR_MIN_RATE_SPS) {
        rate = STEPPER_MOTOR_MIN_RATE_SPS;
    }

    return rate;
}
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

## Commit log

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2026-07-14 Revert "하드웨어 정보 추가"
    This reverts commit 6898570d87d448aad90e76688dd55049f2234d87
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2026-07-14 오타 수정
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2026-07-15 docs: 요구사항 명세서 v0.2 — 기술 스택·KPI·데모 시나리오·팀 분배·로드맵 반영
    - 데모 시나리오(실물1+시뮬 다중, 실물↔미니어처 트윈), 하드웨어·센서·통신 구성
    - 기술 스택 확정(RTMDet/Isaac Sim/ROS2 Nav2/SLAM/Spring Boot/React, MQTT+WebSocket)
    - 박스 단일 클래스 + 학습 데이터셋(LOCO/Roboflow/SKU-110K)
    - KPI, 비범위, FR-505 최적 대수 산출(A수식+B시뮬), 팀 역할 분배, 향후 RL 로드맵
2026-07-15 docs: 요구사항 명세서 v0.3 — 하드웨어 BOM·센서 배치·운용 원칙 반영
    - 하드웨어 BOM: Jetson Orin Nano, 카메라, Nema17 스텝모터+TMC2209+제한스위치, 포크 스텝생성 MCU(Pico2W/STM32), VL53L1X, YDLIDAR X4-Pro, 전면 VL53L8CX
    - 센서 배치·운용 원칙(라이다 레벨/높이, 전면 ToF 저위치+동적 마스킹, travel position)
    - FR-303/304 하드웨어 구체화, 측/후면 저위치 센서 비범위 명시
2026-07-15 docs: 요구사항 명세서 v0.4 — 모터 구성(DC/서보/스텝) 반영
    - BOM: DC 모터(전륜 구동)·서보 모터(조향)·스텝 모터(포크) 각 1개 명시
    - FR-302 구동·조향 제어 반영, Ackermann 구조 → Nav2 회전반경 주의 메모
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2026-07-16 docs: 요구사항명세서 수정(멀티존 ToF 센서 수량 2개로 변경)
2026-07-16 docs: 요구사항명세서 수정(앞선 수정에서 누락된 일부분)
2026-07-16 docs: KPT 회고 가이드·Sprint 0 팀원 회고 기록 추가
    - docs/KPT/KPT-가이드.md: SSAFY Agile 회고방법 정리 (Sprint Complete·번다운·KPT 절차)
    - docs/KPT/Sprint0-KPT.md: Sprint 0 팀원별 Keep/Problem/Try 기록
    - docs/KPT/images/: 원본 교육 슬라이드 6장
2026-07-16 docs: 협업규칙 완화 (Task 허용·스토리 크기 제한 삭제·리뷰 의무 삭제)
    - Jira 계층: Sub-task만 금지하고 Task 유형 허용, 표에 Task 정의 추가
    - Story 1~3일 크기 제한 조항 삭제
    - MR 머지 시 팀원 리뷰 의무 삭제 (리뷰는 선택, MR 경유는 유지)
2026-07-20 docs: 명세서 스프린트 계획·배치 갱신 (난이도 기준 SP 재추정·주차 재배치 반영)
    - §3: 스프린트 목표·이름 확정본으로 교체 (S1 인지·기반 / S2 자율주행+적재추천 / S3 실물통합·트윈·관제)
    - §7: 배치표를 Jira 최신 상태로 교체 — SP 난이도 기준(1/2/3/5), 개인 주차 부하 8~14 SP 평준화
2026-07-20 docs: git-flow 브랜치 모델 도입 (develop 통합 브랜치·release/hotfix 규칙·자동 완료 트리거 변경)
    - master/develop/feature/release/hotfix 브랜치 모델 정의 (컨설턴트 가이드)
    - feature MR 대상 develop으로 변경, 스프린트 종료 시 release→master+태그
    - 이슈 자동 완료 트리거를 기본 브랜치(develop) 머지 기준으로 갱신
    - 기본 브랜치 develop 변경 필요 안내 (Settings→Repository→Default branch)
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2026-07-20 docs: Jira 브랜치 생성 버튼 사용 시 feature/ 접두사 수동 추가 주의사항
2026-07-20 S15P11A304-65 데이터셋 수집·COCO 변환 파이프라인 구축
    - ai/ 디렉터리 골격 신설 (src 레이아웃, editable 설치)
    - CocoBuilder: 소스별 id 재발급·file_name 접두사·경계 bbox 클리핑·중복 제거
    - LOCO/Roboflow(COCO)·SKU-110K(CSV) 변환기, 박스 단일 클래스로 재매핑
    - configs/datasets.yaml로 소스·카테고리 채택 기준 분리
    - 변환 로직 테스트 8건, 데이터 원본은 git 제외
    train/val 분할·라벨 검수는 FR-101-2(S15P11A304-66)에서 진행한다.
2026-07-20 S15P11A304-65 LOCO 실물 데이터 반영 (경로 충돌 수정·pallet 포함)
    실제 LOCO 어노테이션을 받아 검증하면서 발견한 문제를 반영한다.
    - path_key 옵션 추가: LOCO의 file_name은 타임스탬프 basename이라
    subset을 합치면 서로 다른 이미지가 충돌해 덮어써진다. 디렉터리가 담긴
    path를 쓰도록 하고 공통 접두사 /dataset/만 제거한다.
    - keep_categories에 pallet 추가: 포크를 꽂는 대상이라 인식이 필요하다.
    학습 가능 이미지 2,009 -> 4,885장, 박스 27,558 -> 148,003개.
    - 충돌 재현 테스트 2건 추가 (총 10건)
    - README에 실측 클래스 분포와 pallet 편중(81%) 주의사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
2026-07-20 S15P11A304-65 실물 데이터 검증·이미지 존재 확인 기능 추가
    LOCO 이미지 733MB를 실제로 받아 어노테이션과 대조 검증했다.
    - images_root를 실제 구조(data/raw/loco/dataset)로 수정.
    기존 값은 코드에서 쓰이지도 않는 죽은 설정이었다.
    - --verify-images 옵션 추가: 변환 결과의 모든 이미지가 실제로 존재하는지
    확인한다. 경로 규칙 불일치는 학습 단계까지 가서야 드러나므로 변환
    시점에 잡는다.
    - README에 내려받기 절차와 실측 결과 기록
    검증 결과: 어노테이션 5,097장이 실제 파일과 100% 매칭, 해상도 표본 30장
    불일치 0건, 경계 이탈 bbox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
2026-07-20 S15P11A304-65 Roboflow train/valid/test 3개 split 수용
    Roboflow Universe는 COCO 내보내기 시 train/valid/test로 나눠 준다.
    분할은 FR-101-2에서 우리 기준으로 다시 하므로 원본 분할은 무시하고
    세 split을 모두 읽어 합친다. 없는 split은 자동으로 건너뛴다.
2026-07-20 S15P11A304-65 Logistics·Carboard Box 추가, 데이터셋 간 중복 제거
    공개 데이터셋은 서로를 재수록한다. 실측 결과 LOCO 5,097장 중 3,830장(75%)이
    Roboflow Logistics에 그대로 들어 있었다. 파일명이 각각
    subset-1/1564563638.9526272.jpg 와 1564563638-9526272_jpg.rf.<해시>.jpg 라서
    기존 file_name 비교로는 걸러지지 않았다. 이대로 두면 FR-101-2에서 무작위
    분할 시 같은 사진이 train/val에 갈라져 mAP가 부풀려진다.
    - image_identity(): 디렉터리·Roboflow 증강 접미사를 떼고 구분자를 통일해
    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
2026-07-20 docs: 자동 완료 트리거를 develop 기준으로 정정
    git-flow 도입(2026-07-20) 때 5장만 갱신되고 3장·8장은 master 기준
    설명이 남아 문서가 내부적으로 모순이었다. 3장만 읽으면 feature를
    develop에 머지해도 완료가 안 되고 master까지 가야 한다고 오해하게 된다.
    - 3장: master에 머지되면 → develop(기본 브랜치)에 머지되면
    - 8장 트러블슈팅: master 확인 → 기본 브랜치 확인으로 정정하고,
    MR 생성만 해도 이슈 updated 시각이 갱신돼 반영된 것처럼 보이는
    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
2026-07-21 Add new 3D model files for forklift components
    [포크_구성 1_고정부 상단.3mf, 포크_구성 1_고정부 하단.3mf, 포크_구성 1_기둥L.3mf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]
2026-07-21 Add new 3D model file for forklift component
    [포크_구성 1_덥개 탑.3mf]
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2026-07-22 S15P11A304-69 이중 정규화 버그 수정 — 감지 점수 붕괴 해결
    mmdeploy가 export 시 mean/std 정규화를 ONNX 그래프에 내장했는데
    detector가 밖에서 또 정규화 → 이중 처리로 입력이 망가져 점수 붕괴.
    실물 테스트가 잡아냄 (박스 최고점수 0.11).
    수정: 전처리에서 정규화 제거, 원시 BGR 픽셀(float32)만 입력.
    실측 검증: 같은 프레임에서 0.11 → 0.42로 회복, pallet 0.55 감지.
    모델은 정상이었고 전처리 버그였음.
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2026-07-23 S15P11A304-69 미니어처 파렛트·화물 박스 3D 프린트용 OpenSCAD 모델 추가
    - pallet_mini.scad: T-11 파렛트 1/10 (실물 mm→/10 파라메트릭, 포크 fit 검증 echo 포함)
    - boxes_mini.scad: 화물 박스 2호(184×267×152)·2-1호(342×255×105)×2, 실물/10
    - .gitignore로 렌더 STL 제외
    [boxes_mini.scad, pallet_mini.scad]
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2026-07-23 docs: Add troubleshooting guide for Jetson Orin Nano vision environment and PyTorch installation errors
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2026-07-24 S15P11A304-149 미니어처 파렛트 전체 높이 140→120mm 정정
    실물 파렛트 표준 높이(12cm) 기준으로 R_height 정정. 실물 파렛트 수령
    완료로 실측 후 최종 치수 재확인 예정(선행: S15P11A304-150 출력).
    [pallet_mini.scad]
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2026-07-24 S15P11A304-156 파렛트 라벨 수동 수정기 추가
    자동 라벨이 못 한 소수 프레임(33장)을 위해 CVAT에 이미지 200MB를 올리는 대신
    로컬에서 드래그로 그린다. COCO를 직접 읽고 쓰며 원본은 .bak으로 백업.
    - 드래그로 파렛트 작도(기존 파렛트 라벨 대체), ENTER 저장·다음
    - D키로 폐기 표시 → json에서 이미지·라벨 제거
    - 박스(초록) 라벨은 건드리지 않는다
    라벨링 결과: 이미지 289 / 박스 871 / 파렛트 273(자동 240 + 수동 33) / 네거티브 16.
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2026-07-24 docs(KPT): Sprint 1 회고 기록 추가
    번다운 회고(스코프 유입·막판 몰림 분석)와 팀원 6명 Keep/Problem/Try 정리.
2026-07-24 docs(KPT): Sprint 1 회고 팀 최종본 반영
    팀원 6명 Keep/Problem/Try를 주간 회고 확정본으로 갱신.
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2026-07-29 fix: 풀스택 연동 수정
2026-07-29 144 hole 라벨 규약 확정 + 파렛트 실측값 반영
    촬영 착수 전에 라벨 규약을 못 박는다. 300~500장을 찍은 뒤에 클래스나
    규약이 바뀌면 그대로 재작업이라, 첫 배치 전에 정하는 것이 요점이다.
    핵심 결정 — hole은 modal로 그린다(pallet의 amodal 규약을 따르지 않음).
    규약이 클래스마다 다른 이유는 하류가 묻는 질문이 다르기 때문이다. pallet은
    "실제 중심·상단이 어디인가"라서 가려진 부분까지 그려야 하지만, hole은
    "여기 포크를 꽂을 수 있나"다. 가려진 구멍을 열려 있다고 가르치면 포크가
    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
    [pallet_mini.scad]
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2026-07-29 측정 규격 v1.1 — tipping 저장 컬럼 추가 + 버전 올림
    스테이션이 07-28(MR !75)부터 payload에 tipping(전복 위험)을 실어 보내는데
    백엔드가 그걸 모른 채였다. station_measurement 테이블에 컬럼이 없고 DTO에도
    필드가 없다. Spring Boot는 모르는 JSON 필드를 기본으로 무시하므로
    (FAIL_ON_UNKNOWN_PROPERTIES=false) 측정 메시지 자체는 정상 저장되지만
    tipping만 조용히 버려진다 — 에러도 로그도 남지 않아 발견이 늦었다.
    근본 원인은 규격 버전이다. 필드를 추가하면서 schema_version을 "1.0"에 둔 탓에
    소비자가 규격 변경을 감지할 수단이 없었다. 호환을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
2026-07-30 144 로컬 pallet·hole 라벨러 — CVAT 대신 직접 그린다
    fixlabel은 파렛트 하나만 고치는 도구였다. 여기는 한 프레임에 pallet 1개 +
    hole 최대 4개를 그리고 208장을 연속 처리하므로 다중 인스턴스·되돌리기·
    자동 저장·이어하기가 필요하다.
    - 드래그하면 마우스를 뗄 때 바로 확정한다. 208장 × 최대 5개라 확인키를
    두면 손이 두 배가 된다
    - 돋보기(3배, Z) — 개구부가 1280×800에서 세로 25px 남짓이라 1:1로는
    경계가 안 보인다
    - 가이드 §4 검수를 그리는 중에 화면에 띄운다(막지 않고 경고만): pallet
    없이 hole만 · pallet 밖 hole · 종횡비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
2026-07-30 145 승격 게이트 채점 도구 — eval_gates.py
    epoch 116 승격 판정에 쓴 G1~G3 채점 스크립트를 리포에 정식 추가.
    scratchpad 임시본을 경로 인자화(--labels·--img-dir·--neg-dir·--skip)해
    재학습·재평가 때 재사용 가능하게 했다.
    - G1 hole 재현율 ≥95% · G2 pallet 재현율 ≥98% · G3 네거티브 오탐 ≤2%
    (IoU≥0.5, score 0.4). GPU 서버 rtmdet env에서 실행(mmdet 필요).
    - 프레임 3분류: positive(G1·G2) / 네거티브(G3, --neg-dir 포함) /
    스킵(--skip, 블러·잘림·손 침입 — 네거티브로 쓰면 G3 오염).
    - 네거티브 표본 경고: 33장이면 1오탐=3%. --neg-dir로 100장+ 확보 권장
    (2026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
2026-07-30 68 온보드 엔진 완성 — G4 통과 + labels INT64 함정 해결
    epoch 116을 젯슨 TRT FP16 엔진으로 빌드해 G4를 측정, 네 게이트 완주.
    GPU Compute 10.18ms(≤100ms, 97.8fps) — 팀원 경합 중에도 예산의 1/10.
    68 최대 함정(labels INT64):
    - mmdeploy export가 labels를 INT64로 내면 TRT 10.3이 파싱 거부
    (For INT32 tensors, output must be INT32). 07-29 onnx는 INT32라
    빌드됐고 구조는 노드 401개까지 완전 동일 — 차이는 labels dtype뿐.
    - dataset.fix_onnx_labels_int32: labels producer(Reshape) 뒤에 Cast(INT32)
    삽입 + 출력 선언 INT32. 값은 클래스 인덱스라 안전.
    - 진단 방법을 런북에 남김: 새 onnx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
2026-07-31 fix: restore rear-steering Ackermann mapping
    [mapping.py, uart_teleop_bridge.py]
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2026-07-31 feat: 스테이션 계측 및 isaac MQTT 연결 수정
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2026-07-31 feat: Add ToF sensor support and integrate with existing telemetry
    - Introduced `vl53l8cx_pair.h` for ToF sensor initialization and data handling.
    - Updated `sdkconfig.defaults` to configure VL53L8CX sensor parameters.
    - Replaced `imu_bridge` with `sensor_bridge` to handle both IMU and ToF data from a single USB connection.
    - Implemented `sensor_bridge.py` to publish IMU and ToF data as ROS topics.
    - Added `ekf.yaml` for EKF configuration to integrate odometry and IMU data.
    - Updated `sensors.yaml` to include ToF sensor parameters and topics.
    - Modified launch files to include the new sensor bridge and EKF node.
    - Enhanced `sensor_protocol.py` to parse ToF frames and handle multi-zone data.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
    [config.h, main.c, sensor_bridge.py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]
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2026-07-31 docs: Sprint 2 KPT 팀원 6명 Keep/Problem/Try 작성
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2026-07-31 S15P11A304-91 상시 모드 실물 검증 — 버그 셋 수정
    실물로 돌려보니 저장 이미지·단위 테스트로는 안 잡히던 문제가 셋 나왔다.
    1) --listen 이 1회 경로로 샜다. 분기 조건에 not args.listen 이 빠져 있어, cargoId를
    MQTT로 받는 상시 모드를 "cargo-id 없이 보내는 1회 측정"으로 오인했다. 카메라를
    열어 한 번 재고 세션 없이 전송해 400을 받았고 상시 모드는 시작도 못 했다.
    회귀 테스트를 붙였다 - 1회 경로로 새면 이미지 오류 메시지가 찍히므로 그걸로 가른다.
    2) --abandon 이 sessionId 를 안 보냈다. 백엔드가 sessionId 를 필수로 바꿨을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
2026-07-31 kinematics 수정
    kinematics 수정
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2026-08-02 fix: 차량 연동 계약 호환성 보완
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2026-08-03 Refactor ToF sensor initialization and address assignment
    - Updated the ToF sensor initialization process to individually address each sensor, improving reliability during bring-up.
    - Introduced functions for scanning the I2C bus and checking sensor presence.
    - Enhanced error handling for sensor address assignment and added logging for better diagnostics.
    - Added new tools for verifying gyro scale and ToF sensor functionality over USB.
    - Improved code readability and maintainability by restructuring functions and adding comments.
    [config.h, task_motor.c, task_tof.c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]
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2026-08-03 S15P11A304-185 measuredAt 제거 반영 · MR 비강제 방침 명문화
    ## measuredAt
    백엔드 DTO(StationMeasurementCreateRequest)에서 제거됐는데 문서는 "저장 컬럼이
    없어 버려진다"로 남아 있었다. 결과는 같지만 사유가 다르다 — 지금은 계약 자체에
    없고, Spring 이 fail-on-unknown-properties 를 안 켜서 조용히 버려진다.
    저장 시각은 서버 createdAt 이다. 즉시 저장되는 흐름이라 실측에서 두 시각이
    사실상 같았다(12:12:00 vs 12:12:00.376).
    ## 예시의 overhangRatio
    0.057 → 0.04 로 고쳤다. 0.05 **이상**이면 placementEligible 이 false 가 되어
    적재 추천이 나가지 않는다. 정상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
2026-08-03 S15P11A304-186 젯슨 사본 동기화 확인 절차 — md5 대조
    정합 점검에서 젯슨의 추론 서버가 07-31 수정 이전 코드로 돌고 있는 것을 발견했다.
    레포는 고쳤는데 손으로 복사하는 구조라 보드에 3일간 반영되지 않았다.
    빠진 것이 하필 사고 방지 장치였다 — TrtDetector 에 class_thresholds={} 를
    넘기지 않아 온보드용 기본값(pallet 0.7)이 스테이션 경로에 적용됐다. 스테이션
    임계는 0.4 라서 score 0.4~0.7 파렛트가 보드에서만 버려지고, 같은 장면이 로컬은
    ok / 보드는 dimensions_only 가 된다. 전복·편하중이 통째로 빠지는데 에러는 안 난다.
    당시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
2026-08-03 S15P11A304-188 백엔드 사전 확인의 import 누락 수정
    직전 커밋에서 base_url_of/active_session 을 상시 모드 분기에 쓰면서 import 를
    빼먹어 NameError 가 났다. 두 이름은 --check 분기 안에서만 import 돼 있었다.
    테스트가 잡아줬다(test_listen은_cargo_id_없는_1회경로로_새지_않는다). 다만
    직전 커밋을 테스트 결과를 확인하기 전에 푸시한 것이 잘못이었다 — 실패한 채로
    원격에 올라갔다.
    222개 통과.
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2026-08-03 S15P11A304-193 no-spin 행동트리가 만들어져 있고 안 쓰이고 있었다
    젯슨에 Nav2 를 실제로 띄워보니 복구 동작에서 spin 이 돌았다.
    behavior_server: spin failed
    behavior_server: Running backup → Collision Ahead → failed
    spin 은 `linear.x=0, angular.z≠0` 을 내는데, 모터 브리지가 전진 성분 없는
    명령을 데드밴드로 걸러 **구동 0 · 조향 중립**을 돌려준다(mapping.py). 뒷바퀴
    조향은 제자리 회전이 불가능하니 그 처리가 옳다 — 즉 spin 은 **매번 실패한다.**
    ## 고칠 게 트리가 아니라 배선이었다
    `navigate_to_pose_no_spin.xml` 이 **07-31부터 레포에 있었다.** 주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
2026-08-04 S15P11A304-196 shoot.py --headless — SSH 로 젯슨에서 촬영할 수 있게
    CAP_DSHOW 를 고쳐 카메라는 열렸는데 다음 줄에서 죽었다.
    cv2.error: Can't initialize GTK backend in function 'cvInitSystem'
    SSH 세션에는 디스플레이가 없어 미리보기 창을 못 띄운다. `--auto` 도 루프
    안에서 imshow 를 부르므로 같이 죽는다 — **화면 없이 찍을 방법이 없었다.**
    ## --headless
    미리보기를 끄고 `--auto` 간격으로만 저장한다. 저장할 때마다 stdout 에 한 줄씩
    남긴다 — 화면이 없으니 이게 없으면 "돌고는 있는데 찍히는지 모르는" 상태가 된다.
    [ 1] 저장 onb_20260804-093711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
2026-08-04 fix: 측정 설비 점유 시 요청 대기 처리
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2026-08-04 feat: 측정 실패 원인 코드 대시보드 노출 및 관제 화면 실패 카드 추가
    측정 부적합/미응답 등 실패 원인을 TaskFailureCode로 기록하고 대시보드
    FailureView로 노출한다. 관제 프론트에는 실패 카드·AI 측정 프리뷰·차량
    우선순위 정렬을 추가한다.
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2026-08-04 S15P11A304-197 조향 원점 이동을 되돌린다 — 펌웨어까지 고쳐야 한다
    직전 커밋에서 center 를 10000 → 11500 으로 옮겼는데 **브리지가 즉시 죽었다.**
    protocol.py:53 ValueError: steering_cdeg must be between 8500 and 11500
    [ERROR] process has died [pid 17930, exit code 1]
    `mapping.py` 의 검증만 넓히고 **`protocol.py` 를 놓쳤다.** 그리고 찾아보니 같은
    8500~11500 상한이 **네 곳**에 박혀 있다:
    ① mapping.py TeleopLimits.validate() ← 넓혔음
    ② protocol.py encode_command() ← 여기서 죽었다
    ③ 펌웨어 config.h TELEOP_STEERING_MIN/MAX_CDEG
    ④ 펌웨어 task_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
2026-08-05 S15P11A304-152 조향 펄스 범위 수정 · 45° 파렛트 관통
    서보가 명령의 절반만 돌고 있었다. servo_set_angle() 이 각도를 180 으로
    정규화해 SERVO_MIN/MAX_PULSE_US 사이에 매핑하는데 그 범위가 1000~2000us
    였다. MG996R 은 500~2500us 가 180° 이고 1000~2000 으로는 90~120° 밖에
    안 돈다. 뒷바퀴 실측 8°(코드는 28° 로 믿음), 실효 회전반경 1200~1450mm
    (설계값 537mm 의 2~3배), 명령 대비 실제 회전 21~26% 가 tan(8)/tan(28)=25%
    로 맞물려 확인됐다.
    이 하나가 ALIGN 요각 미교정 · 45° 발산 · 한계진동의 공통 원인이었다.
    펌웨어·설정
    - SERVO_MIN/MAX_PULSE_US 1000~2000 -> 500~2500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
    [config.h, mapping.py, uart_teleop_bridge.py]
2026-08-05 S15P11A304-202 낡은 기술 정합 점검 — 기본값·도움말·테스트·문서
    08-05 조향 펄스 범위 수정 이후, 바뀐 사실 위에 옛 기록이 남아 있는 곳을
    두 번 훑었다. 2회차에서 실동작에 닿는 것이 나왔다.
    기본값·도움말
    - TeleopLimits.max_angular_rps 가 0.35 인 채였다. teleop.yaml 은 08-05 에
    0.75 로 올라갔는데 dataclass 만 안 따라왔다. 바로 아래 주석이 "이 기본값들은
    계속 낡은 채 방치되는 자리다" 라고 경고하는데 steering_* 만 고치고 지나쳤다.
    브리지는 늘 yaml 을 넘기므로 지금 동작에는 영향이 없다 — 인자 없이
    TeleopLimits() 를 만드는 코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
    [mapping.py]
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2026-08-06 S15P11A304-178 14회차 — 내 08-05 판정 정정 · 데이터 계층 대조
    wireframe-monitoring-final.md
    - 08-05 에 내가 "`/topic/vehicles/result` 구독도 없다" 고 적었는데 **틀렸다.**
    hooks/useMonitoringSocket.ts 가 TOPIC_VEHICLE_RESULT 로 실제 구독하고 있다.
    토픽 문자열이 types/websocket.ts 에만 보이는 것을 미구독으로 읽었는데, 상수를
    타입 파일에 정의하고 훅에서 import 하는 구조였다. 문자열 위치가 아니라
    subscribe( 호출을 봐야 한다.
    - RESET_ESTOP 은 재확인해도 타입뿐이라 그 항목은 그대로 유효하다.
    - §2 항목별 현재 상태를 표로 다시 적었다.
    같이 대조하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
2026-08-06 S15P11A304-178 20회차 — UART 응답 규격에 ERROR 가 빠져 있었다
    firmware README 는 "정상 수신 응답: @ACK,<seq>,OK" 한 줄만 적고 있었다. 실제로는
    펌웨어가 `send_error_ack()` 로 **@ACK,<seq>,ERROR** 도 보내고(task_comm.c:275·468·523),
    브리지 파서도 {"OK","ERROR"} 둘 다 받는다(protocol.py:134).
    빠져 있던 것이 규격 한 줄만이 아니라 **디버깅에 필요한 구분**이었다:
    - 프레임이 깨졌으면(CRC·길이·범위 밖) **아무 응답도 없다** — 시퀀스를 신뢰할 수 없어
    조용히 버린다. 배선·전송 문제다.
    - 프레임은 멀쩡한데 실행을 거부하면 **ERROR 응답**이 온다. 펌웨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
2026-08-06 Refactor forklift teleop protocol and enhance functionality
    - Updated protocol.py to align steering and drive limits with firmware configurations, ensuring consistency and preventing errors.
    - Enhanced command encoding for lift actions to include new commands (HOME, INITIALIZE).
    - Improved error handling and validation in command encoding and parsing functions.
    - Adjusted lidar_odometry.launch.py to correct LIDAR rotation for accurate odometry.
    - Introduced nav2_forklift.launch.py to integrate custom behavior tree for navigation without spinning.
    - Added obstacle_avoidance.launch.py to manage nominal velocity through obstacle guard.
    - Updated sensor_usb.launch.py with precise sensor transfor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
    [config.h, encoder.c, main.c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]
2026-08-06 Enhance forklift teleoperation and sensor protocols
    - Added TofStatusFrame and EncoderFrame data classes to support new sensor data types in sensor_protocol.py.
    - Updated parse_sensor_line function to handle new TofStatusFrame and EncoderFrame types.
    - Modified uart_teleop_bridge.py to include additional fork commands (HOME, INITIALIZE) and improved handling of fork command queue.
    - Adjusted TeleopLimits initialization to avoid hardcoding parameters in uart_teleop_bridge.py.
    - Updated package.xml description to reflect broader functionality.
    - Enhanced setup.py to include RViz configuration files and added obstacle avoidance node to console scripts.
    [mapping.py, sensor_bridge.py, sensors.yaml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]
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2026-08-06 feat: 차량 경로 충돌 예측 및 안전거리 제어 (FR-502-1a)
    ROS2/Isaac 이 MQTT 로 보내는 위치·상태를 백엔드 메모리에서 판단해 후행 차량에
    STOP/RESUME 을 발행한다. 판단 근거는 traffic_control_event 에 남긴다.
    구현
    - CollisionPredictor: 예측 위치·유효 거리·접근 판정·구역 침범을 순수 함수로 분리.
    스프링/DB/MQTT 를 모르게 두어 단위 테스트로 고정했다 — 이 로직이 틀리면 차량이
    안 멈추거나 영영 못 가는데, 통합 환경에서는 재현이 어려운 종류다.
    - WorkZoneRegistry: 선반 작업 구역 점유를 매 tick 새로 계산한다. 누적하지 않으므로
    해제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
2026-08-06 fix: 교통 관제 RESUME 이 Isaac 제어 토픽으로 발행되지 않던 문제 (FR-502-1a)
    VehicleCommandType 에 RESUME 을 추가하면서 publishIsaacControl 의 변환표를 갱신하지
    않았다. 그 결과:
    STOP -> "HOLD" 발행됨
    RESUME -> default null 로 빠져 **발행조차 안 됨**
    교통 관제가 차량을 세우기는 하는데 재개 신호가 Isaac 에 전혀 도달하지 않아,
    **한 번 멈춘 차량이 영영 다시 가지 않는** 상태였다. 백엔드 로그에는 "교통 관제 재개" 가
    찍히고 DB 에도 RELEASE 이벤트가 남아서, 로그만 보면 정상으로 보이는 것이 더 나쁘다.
    Isaac 제어 계약에는 정지 해제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
2026-08-06 fix: Isaac control 페이로드에 규격 필수 필드 ts 추가
    isaac_sim/docs/interface-spec.md §3.2 가 정한 control 계약은
    { "ts": 1784568107610, "command": "ESTOP" }
    command: ESTOP | RESUME | HOLD | CANCEL_TASK
    인데 백엔드는 command 만 보내고 ts 를 빠뜨리고 있었다. 수신 측이 ts 를 필수로 읽으면
    명령이 조용히 무시된다 — 발행은 성공하고 차량만 반응하지 않아 원인을 찾기 어렵다.
    같은 문서가 HOLD 를 "FR-502 교차 제어용"으로 명시하고 있어, 교통 관제의 STOP -> HOLD /
    RESUME -> RESUME 변환은 규격과 일치한다(방향은 맞았고 필드만 빠져 있었다).
    IsaacVehicleControlMess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
2026-08-06 fix: 실물 오린카 fk01 차량 ID 별칭 추가
    F팀 backend-mqtt-guide(2026-08-05) 계약의 차량 ID 는 sim02 / sim03 / fk01 인데,
    fk01 만 별칭이 없어 auto-registration 이 이를 **별개 차량으로 새로 등록**하고 있었다.
    로컬 대시보드에서 vehicleId="fk01", name="fk01" 로 잡혀 있는 것을 확인했다
    (REAL-F01 과 같은 차량인데 관제 화면에는 둘로 보인다).
    같은 문서가 알린 sim01 -> sim02/sim03 개편도 주석에 남겼다. sim01 별칭은 구 발행자가
    남아 있을 수 있어 지우지 않았다.
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2026-08-07 fix: 검출 상자를 AI 측정 영상에 실제로 연결 (미배선 보완)
    직전 커밋(efa8295)에서 AiMeasurementVideo 가 boxes 를 받을 수 있게만 해 두고 상위에서
    넘기지 않아, **사각형이 절대 그려지지 않는 상태**였다. 컴포넌트만 고치고 배선을
    빠뜨리면 컴파일도 테스트도 통과해서 눈치채기 어렵다.
    연결한 경로
    백엔드 /topic/stations/measurements
    → useMonitoringSocket 구독(onMeasurementEvent)
    → page.tsx lastMeasurement 상태
    → AiMeasurementVideo boxes/frameWidth/frameHeight (PIP·전체보기 두 곳 모두)
    측정 이벤트만 parseRealtimeEvent 를 쓰지 않는다
    - 공통 envelope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
2026-08-07 fix: 랙 슬롯 DB 시드 데이터 정비
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2026-08-07 DDS 공유메모리를 끈다 — 통신 이상의 근원이었다
    노드가 정상 종료가 아니라 강제로 죽으면 /dev/shm 에 포트 잠금과 세마포어만
    남고 세그먼트는 사라진다. 이후 그 포트에 걸리는 참가자는
    RTPS_TRANSPORT_SHM Error ... open_and_lock_file failed
    를 찍고 **조용히 그 포트를 잃는다.** 하루 동안 이것이 일으킨 피해:
    - 액션 목표 응답 유실. bt_navigator 는 NavigateToPose 를 수락했는데 응답이
    못 돌아와, 클라이언트는 "거부됨" 으로 보고 차는 출발했다. 서로 다른 상태를
    믿고 있었다.
    - 구독이 안 붙음. 가드가 20 Hz 로 멀쩡히 발행하는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
2026-08-07 후진 계획 허용, 복구는 이 차에 듣는 순서로
    전진 전용(DUBIN)이면 **나올 길이 없는 자리가 생긴다.** 2 x 3 m 목업에서 실제로
    그랬다: 앞이 정지 임계에 닿고 좌우 회전 여유도 없어, 사람이 손으로 빼기 전엔
    못 움직였다. 원래 주석의 전제("unsensed reverse motion 을 피한다")는 360도
    라이다 후방 감시와 rear_stop_distance_m 가 생기면서 이미 바뀌어 있었다.
    곧은 후진은 실측으로 잘 된다(-0.25 m/s).
    복구 순서를 뒤집었다. RoundRobin 이 costmap 비우기부터 돌고 있었는데, 물리적
    으로 출발을 못 하는 차에게 지도를 지워 주는 것은 아무 효과가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
2026-08-08 목업보다 넓은 팽창 반경이 앞뒤 반복을 만들고 있었다
    RViz 로 goal 을 주면 차가 전진·후진을 끝없이 되풀이했다. 가드도 탈출 후진도
    원인이 아니었다 -- 50초 동안 가드 STOP 은 1회뿐이었고 탈출은 한 번도 안 나섰다.
    순환은 이랬다:
    전진 -> RPP `collision ahead` (50초에 166회)
    -> Controller patience exceeded (42회)
    -> 복구 BackUp -> **그것도 즉시 collision 으로 실패** (9회)
    -> Wait 3초 -> 재계획 -> 전진
    원인은 inflation_radius 0.55 다. 이 지도에서 벽에서 가장 멀리 떨어질 수 있는
    거리가 **0.595 m 뿐**이라, 0.55 면 거의 모든 칸이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
2026-08-09 백엔드 관제 문서 작성
    백엔드 관제 문서 작성
    [rack_slots.csv]
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2026-08-09 uart_teleop_bridge.py 줄바꿈을 LF 로 (내용 변경 없음)
    이 파일만 CRLF 였고 나머지 파이썬 소스는 전부 LF 다. 섞여 있으면 편집 도구에
    따라 전체가 diff 로 잡혀 **실제 변경이 묻힌다** -- 직전 커밋에서 26줄 수정이
    1238줄로 보였다.
    내용은 한 글자도 안 바뀐다. `git show -w` 로 확인할 수 있다.
    [uart_teleop_bridge.py]
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2026-08-09 조건 수정
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2026-08-09 fix: 랙 fork_height 10배 오류 정정 (13.25 → 1.325)
    F팀 8/5 판 표의 "선반 높이 13.25" 를 그대로 시드에 넣었는데, 8/9 개정판 높이
    환산표·nav2/config/rack_slots.csv(place_z)·backend-control-impl 의 shelfHeight
    예시가 모두 1.325 다. 13.25 는 문서상 포크 최대치 1.5 를 8 배 넘는 값이다.
    fork_height 는 task.dropoff.forkHeight 로 변환 없이 그대로 나가므로 틀린 값이
    차량에 직접 전달된다. 로컬·EC2 운영 DB 양쪽에 이미 들어가 있어 정정용 SQL 을
    함께 둔다(fix-fork-height.sql — fork_height 한 컬럼만 바꿔 예약·적재 상태를
    건드리지 않는다).
    시드 주석의 "시뮬 좌표를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
2026-08-09 fix: DB 문자셋을 utf8mb4 로 — 한글이 물음표로 저장되던 문제
    관제 화면 차량 이름이 `????? ??? 1?` 로 나왔다. 물음표 개수가 원래 글자 수
    ("시뮬레이션 지게차 1호" 10자)와 정확히 일치한다.
    db/schema.sql 에 CHARACTER SET 지정이 하나도 없어서 DB 기본 문자셋(latin1)으로
    테이블이 만들어졌다. JDBC URL 의 characterEncoding=UTF-8 은 연결 인코딩일 뿐이라,
    컬럼이 한글을 담지 못하면 MySQL 이 표현 불가 문자를 '?' 로 바꿔 저장한다.
    - schema.sql: 10개 테이블 전부 utf8mb4 명시 + 재발 경고 주석
    - fix-charset-utf8mb4.sql: 기존 DB 변환용
    ALTER DATABASE 만으로는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
2026-08-09 S15P11A304-154 진입 실패 판정·재접근 — 정체 판정과 비정상 오차 가드
    VERIFY 에서 튄 한 프레임으로 진입이 확정되던 문제 위에, 재접근이 성과 없이
    반복되는 경우와 오차 추정 자체가 틀린 경우를 따로 끊는다.
    - `_implausible()` — 요각이 물리적으로 불가능하거나(±60°), 두 구멍 폭이
    서로 3할 이상 어긋나면 그 프레임의 오차를 믿지 않는다. 값이 튄 채로
    조향에 들어가면 멀쩡한 정렬을 스스로 망가뜨린다.
    - `STALL_VERDICT_RETREATS` — 재접근을 두 번 해도 판정이 나아지지 않으면
    같은 자리를 왕복하는 것이므로 ABORT 한다.
    - `CONT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
2026-08-09 비전 파렛 진입을 잇는다 — 없던 것은 노드 하나였다
    `fork_servo.py:13` 이 **"ROS2 배선은 fork_align_node.py"** 라고 적고 있는데
    그 파일이 없었다. 상태기계(1537줄)도, 구멍 검출도, 미션 쪽 계약
    (`/align/request` · `/align/result`)도, 운전 권한 중재(ALIGN 모드)도 전부
    만들어져 있었지만 **셋을 잇는 노드가 없어 아무것도 돌지 않았다.**
    `/mission/task` 에 구독자가 없던 것과 같은 종류의 구멍이다.
    이 노드는 새 판단을 하지 않는다. 카메라 -> TrtDetector -> eligible_targets ->
    AlignTarget.error() -> YawSmoother -> ForkServo.step() -> /cmd_vel_align 을
    잇고, 단계 전환에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
2026-08-09 fix(fork): 진입 중에 포크를 건드리지 않고, 넣은 뒤에 띄운다
    포크 명령이 틀린 단계에 걸려 있어 파렛에 포크가 제대로 들어가지 않았다.
    INSERT 는 포크가 구멍으로 미끄러져 들어가는 구간이다. 거기서 UP 을
    보내면 날이 구멍 상판을 밀어 **진입 자체가 막힌다.**
    RETREAT 는 최종 후퇴가 아니라 **재접근용 후진**이다(MAX_RETRIES=20,
    로그 "미정렬 — 80mm 물러난다 1/20"). 거기서 DOWN 을 보내면
    정렬 도중에 높이가 어긋난다.
    fork_servo 는 리프트를 아예 모른다 — 구멍에 넣는 주행까지만 하고 들어올리는
    것은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
2026-08-09 S15P11A304-119 마이그레이션 확인 SELECT 의 별칭을 ASCII 로
    한글 별칭을 쓰면 클라이언트 접속 문자셋에 따라 파이프로 넣을 때 깨져 ERROR 1064 로
    죽는다. EC2 실행에서 실제로 났다(2026-08-10).
    ERROR 1064 at line 112 ... near '??,\n COUNT(*) AS 칸수, ...'
    **UPDATE·INSERT 는 그 앞이라 이미 적용된 뒤였다.** 스크립트 전체가 실패한 것처럼
    보여서 더 헷갈린다 — 되돌리려다 이미 들어간 24칸을 두 번 넣을 뻔했다(INSERT IGNORE
    라 무해했지만 의도한 안전장치는 아니었다).
    값 자체는 정상 반영됐다.
    L0_floor 24칸 usable_height 0.14 fork_height 0.0
    L1_she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
2026-08-09 S15P11A304-119 적재 칸이 OCCUPIED 로 안 바뀌었다 — 화물 레코드를 함께 만든다
    EC2 에서 0층 적재가 성공했는데(주기 완료 2회) storage_slot 은 48칸 전부 EMPTY 였다.
    로그에 원인이 있었다.
    ERROR 적재 칸 상태 기록 실패(격리됨): slotCode=AF01
    Check constraint 'chk_storage_slot_state' is violated.
    SQL: UPDATE storage_slot SET status='OCCUPIED' WHERE slot_code=? AND status='EMPTY'
    제약이 이렇다(schema.sql:114).
    (status = 'OCCUPIED' AND reserved_task_id IS NULL AND stored_cargo_id IS NOT NULL)
    OCCUPIED 는 화물 ID 를 요구하는데 주기 상태기계에는 운반 작업이 없어 줄 ID 가 없었다.
    ##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
2026-08-12 fix(docs): mermaid 가 GitHub 에서 렌더되도록 비표준 문법을 걷어낸다
    GitHub 이 Cannot read properties of undefined (reading render) 로 실패했다. 노드 라벨의 b/i 태그, 양방향 점선 화살표, 화살표 없는 링크, subgraph 에 classDef 적용을 모두 표준 문법으로 바꿨다. 중괄호가 들어간 토픽 문자열도 라벨에서 뺐다.
2026-08-12 fix(docs): 다이어그램 줄바꿈과 테마 대비를 고친다
    GitHub 은 mermaid 를 htmlLabels 없이 렌더해서 br 태그가 통째로 사라졌다. 그래서 1) FrontendNext.js 16.2.6 처럼 줄이 붙어버렸다. 백틱 마크다운 문자열로 바꿔 줄바꿈이 살아나게 했다. 그룹 배경을 밝은 색으로 칠해뒀더니 GitHub 다크 테마에서 어두운 노드와 부딪혔다. 배경을 빼고 테두리 색만 남겨 두 테마 모두에서 읽히게 했다. Jetson 제원이 subgraph 제목에 들어가 가로로 길게 늘어나던 것을 안쪽 노드로 옮겼다.
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2026-08-12 fix(docs): 범례 색 표시를 이모지로 바꾼다
    GitHub 이 마크다운의 인라인 style 속성을 지워서 색 네모가 전부 무채색으로 나왔다. 색을 못 보여주면 범례가 할 일을 못 한다.
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2026-08-12 fix(readme): 편하중 정상 사진의 ratio_x 값을 바로잡는다
    정상 적재 사진의 실제 오버레이는 ratio_x -0.052 인데 0.038 로 적혀 있었다. 0.038 은 08_라이브검증_스테이션.png 의 값이다 — 다른 사진 값을 가져다 붙였다. 실물에서 잰 값이라고 써놓고 숫자가 사진과 다르면 나머지 수치도 의심받는다.
    포크 정렬 45도 관통은 표본 1회임을 명시했다. 저장소 구조에서 빠져 있던 hardware/ scripts/ 발표자료/ 를 넣었다.
2026-08-12 fix(readme): 자율 프로젝트를 공통 프로젝트로 바로잡는다
    근거 없이 자율로 적었다. 이력서에 붙는 문서라 과정 이름이 틀리면 면접에서 바로 걸린다.
